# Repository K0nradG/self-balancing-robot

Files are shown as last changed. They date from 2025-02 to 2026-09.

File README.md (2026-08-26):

# Self-Balancing Robot

<p align="center">
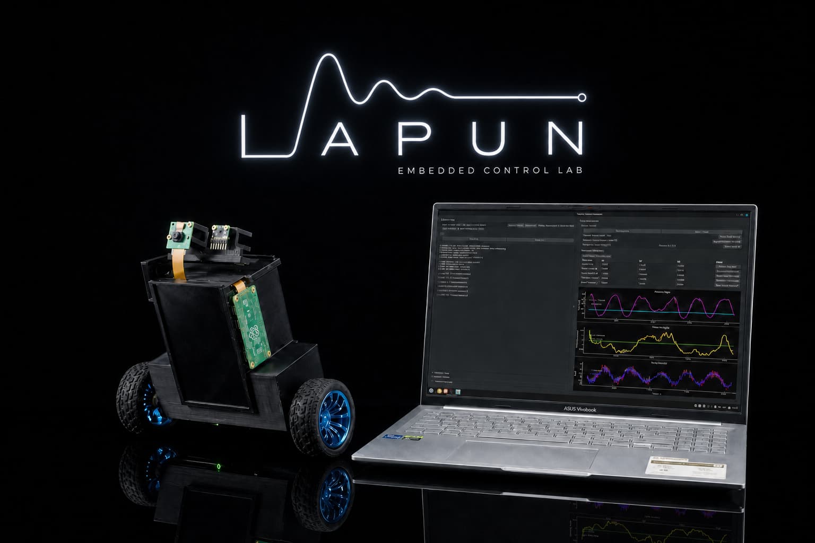
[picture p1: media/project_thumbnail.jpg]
Self-Balancing Robot and Control Application
  
</p>

A two-wheeled self-balancing robot built around the **Nordic nRF52840** and
**Zephyr RTOS**, using **nRF Connect SDK 2.8.0**. The project includes the
embedded control system, custom electronics and mechanical designs, a BLE
desktop application, over-the-air firmware updates, and tools for modelling
and controller development.

## Documentation

- [Project overview](README.md)
- [Environment setup](docs/environment_setup.md)
- [Building and flashing](docs/building_and_running_fw.md)
- [BLE protocol](Sources/drivers/bluetooth/README.md)
- [Control-loop structure](Sources/robot_control/docs/control_loop.md)
- [Application state machine](Sources/robot_control/docs/application_state_machine.md)
- [Mathematical model](mathematical_model/doc/model.md)

## Demonstration

https://github.com/user-attachments/assets/bdc0d3e3-bf6b-4125-bade-0684ad42b085

> 🎥 **See the robot in action!** 
> Check out the [Lapun Embedded Control Lab](https://youtube.com/@lapunembededcontrollab) on YouTube for more demonstrations.
>
> 

## Features

### Robot firmware

- Cascaded control loop for balancing, driving, and rotation
- PID controllers with user-adjustable setpoints and parameters
- Optional LQR balance controller
- Trajectory generation for linear motion and rotation
- MPU6050 inertial measurement and quadrature encoder feedback
- PWM motor control through a dual-channel TB6612FNG driver
- Battery-voltage monitoring
- Safety angle validation and controlled motor shutdown
- Binary BLE protocol for commands, telemetry, and diagnostic logs
- MCUboot-based device firmware update over BLE

### Control and development tools

- PyQt6 desktop application for BLE control, live telemetry, PID tuning, and DFU
- Offline model identification and LQR tuning tools
- MATLAB/Simulink models of the inverted-pendulum system
- Optional Raspberry Pi Zero 2 W web interface with camera streaming
- KiCad schematics, PCB layout, Gerber files, and mechanical CAD

> [!NOTE]
> The default firmware configuration uses PID control. The LQR controller and
> on-device model-identification mode are implemented but disabled by default.
>
> The Raspberry Pi web interface and the nRF7002 DK controller are legacy or
> experimental components and may require adaptation to the current binary BLE
> protocol.

## Control architecture

The firmware uses a cascaded control structure. Distance and linear-speed
controllers generate the balance-angle setpoint, while the balance and
rotation controllers determine the wheel-speed setpoints. Separate wheel
controllers then generate the motor PWM outputs.

Control loop architecture

## Hardware

The robot is based on:

- Nordic nRF52840 Dongle
- MPU6050 IMU
- Two DC gearmotors with quadrature encoders
- TB6612FNG dual motor driver
- 2-cell, 7.4 V LiPo battery
- Custom PCB and 3D-printed mechanical structure
- Optional Raspberry Pi Zero 2 W and CSI camera

Hardware design files are available in [`Schematic/`](Schematic/).

### Custom PCB

<p align="center">
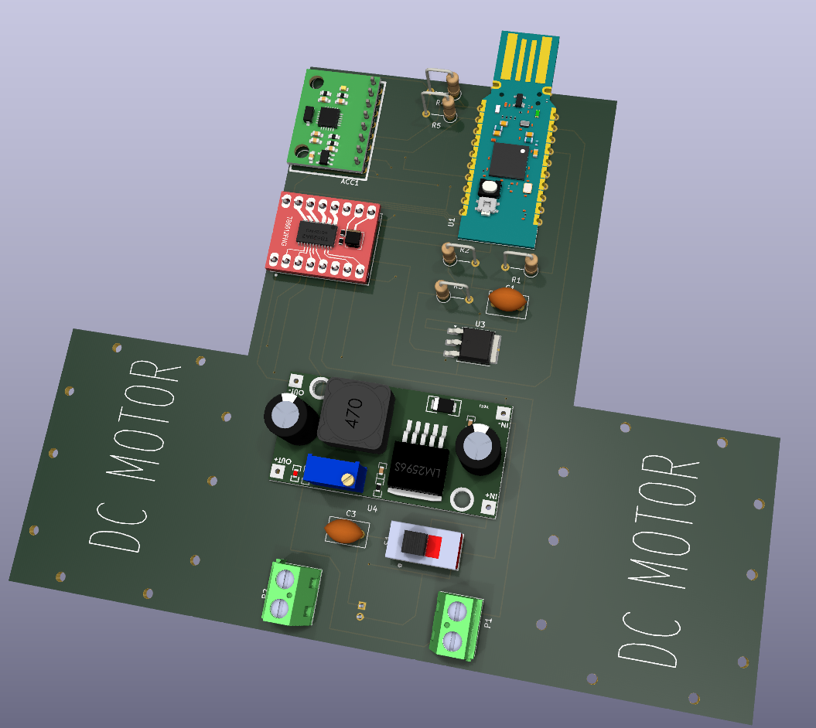
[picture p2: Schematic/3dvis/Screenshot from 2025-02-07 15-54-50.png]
Custom self-balancing robot PCB render
  
</p>

<p align="center"><em>3D render of the custom robot controller PCB.</em></p>

## Getting started

### Prerequisites

- [nRF Connect SDK 2.8.0](https://developer.nordicsemi.com/nRF_Connect_SDK/doc/2.8.0/nrf/index.html)
- nRF Connect toolchain 2.8.0
- West and the Zephyr development environment
- An external SWD debugger for the initial firmware installation

Follow the [environment setup guide](docs/environment_setup.md) before
building the project.

### Build the robot firmware

From the repository root:

```bash
cd Sources/applications/app
west build -b nrf52840dongle_nrf52840 -p always
```

A successful build generates:

```text
Sources/applications/app/build/merged.hex
Sources/applications/app/build/dfu_application.zip
```

The firmware can also be built through nRF Connect for VS Code. See
[Building and flashing](docs/building_and_running_fw.md) for the complete GUI,
terminal, SWD, and BLE DFU workflows.

### Flash the initial firmware

After connecting an external SWD debugger:

```bash
cd Sources/applications/app
west flash --erase --skip-rebuild
```

Subsequent firmware versions can be installed over BLE using the desktop
application or the command-line DFU tool.

### Run the desktop application

The desktop application requires Python 3, PyQt6, Bleak, and PyQtGraph:

```bash
python3 -m pip install PyQt6 bleak pyqtgraph
python3 run_controller_app.py
```

The DFU workflow additionally requires
[`smpmgr`](https://github.com/intercreate/smpmgr). A Windows binary is included
in [`3rdParty/smpmgr/`](3rdParty/smpmgr/); on Linux, `smpmgr` must be available
on `PATH`.

## Repository structure

```text
.
├── Sources/applications/app/          # Main nRF52840 robot firmware
├── Sources/applications/controller/   # Experimental nRF7002 DK controller
├── Sources/applications/controller_rpi/
│                                      # Raspberry Pi web interface
├── Sources/drivers/                   # IMU, encoders, motors, BLE, DFU, battery
├── Sources/robot_control/             # Control loop, PID, LQR, state machines
├── robot_control_app/                 # PyQt6 BLE desktop application
├── mathematical_model/                # Models, identification, and LQR tooling
├── Schematic/                         # PCB, schematics, Gerbers, and CAD
├── docs/                              # Setup and build documentation
└── dts/bindings/                      # Custom Zephyr devicetree bindings
```

## Roadmap

- Swing-up procedure
- Neural and other intelligent controllers
- Vision-based autonomous navigation

## Licensing

- Software and firmware: [Apache License 2.0](LICENSE)
- Hardware designs (schematics, PCB, and CAD):
  [CERN-OHL-P-2.0](Schematic/LICENSE)

Commercial use is permitted under the terms of the respective licenses.

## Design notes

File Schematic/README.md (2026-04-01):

## License

This project is licensed under the **CERN Open Hardware Licence Version 2 - Permissive (CERN-OHL-P)**. 

The license covers all design files in this directory, including:
* **Electronics:** KiCad schematics, PCB layouts, and libraries.
*  **Mechanics:** Physical case design (Fusion 360 files in the `robot-case` directory).

Copyright © 2026 Dymczyk Filip and Konrad Grucel

# **Project Based on KiCad 7.0**

## **Generating Gerber Files**

To generate new Gerber files after making changes to the schematic, follow [this guide](https://jlcpcb.com/help/article/how-to-generate-gerber-and-drill-files-in-kicad-7).

### **Quick Guide**

1. Open the PCB editor.
2. Click **File → Fabrication Outputs → Gerber Files (.gbr)**.
3. Your configuration should look like the following image:

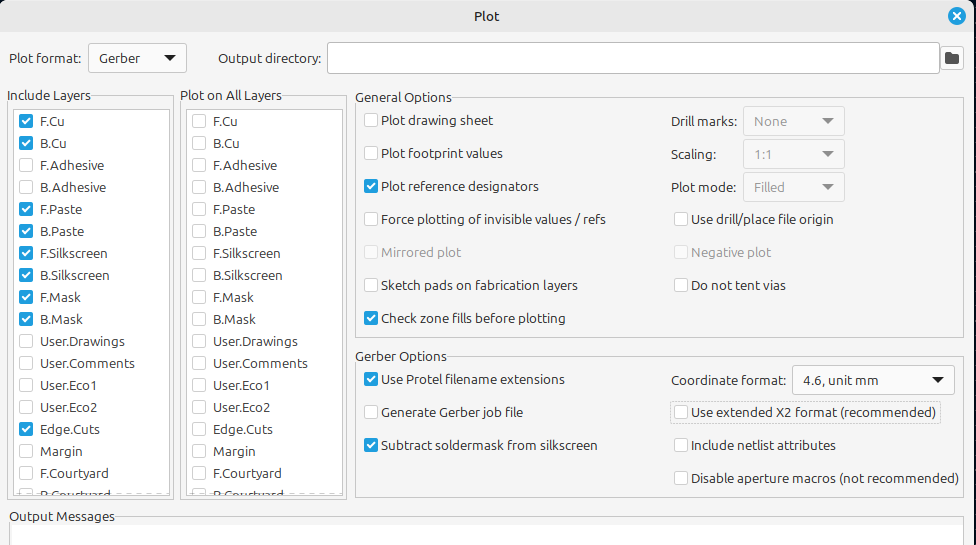
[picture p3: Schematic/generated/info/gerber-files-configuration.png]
.gbr files configuration


4. Click **Plot**, and the files will be saved in your selected output directory.

For drill files **.drl**, follow these steps:

1. Configure settings as shown below:

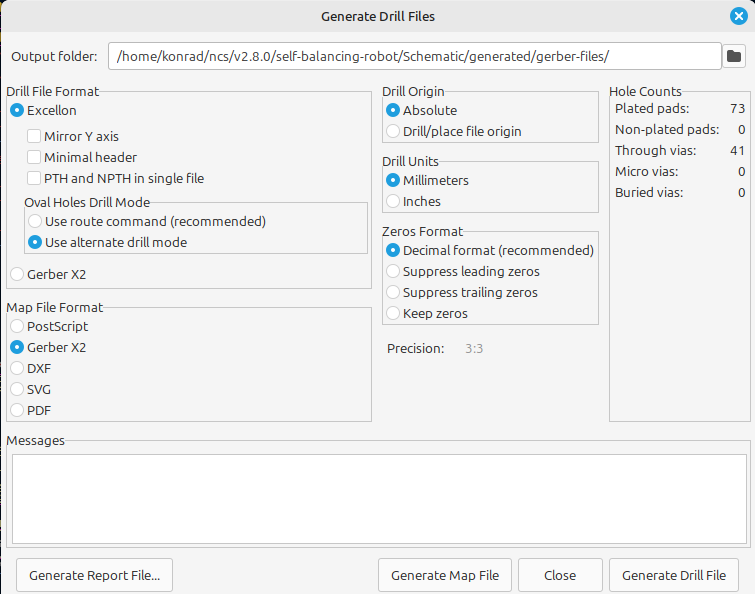
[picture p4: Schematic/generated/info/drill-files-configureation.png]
.gbr files configuration


1. Click **Generate Drill Files**, then **Generate Map Files**.
2. The files will be saved in your selected output directory.

**Adding Custom Symbols, Footprints, and 3D Models**

### **Sources for Custom Components**

You can find various custom symbols, footprints, and 3D models online. Recommended sources:

- [GrabCAD](https://grabcad.com/library/lm2596-module-for-kicad-1)
- [SnapEDA](https://www.snapeda.com/parts/GY-521/GODREAM FORDREAM CO., LIMITED/view-part)

All external symbols, footprints, and 3D models used in this project are located in the `external-3d-models` and `external-symbols-footprints` directories. The sources for these components are documented in `utils/external-parts-Kicad.txt`.

### **Adding Symbols and Footprints**

#### **1. Download the Files**

Example files from [SnapEDA](https://www.snapeda.com/parts/GY-521/GODREAM FORDREAM CO., LIMITED/view-part):

- **Symbol:** `.kicad_sym`
- **Footprint:** `.kicad_mod`

#### **2. Adding a Symbol**

1. Open the KiCad schematic editor.
2. Click **Preferences → Manage Symbol Libraries**.
3. Click the folder icon and provide the path to the `.kicad_sym` file.

#### **3. Adding a Footprint**

1. Open the KiCad schematic editor.

2. click the following icon

   .gbr files configuration

3. Click **Preferences → Manage footprints Libraries**,  and provide an path to the `.kicad_mod` file

next you have to click `Preferences button` button and then `Manage footprints liblaries`

then you have to click `directory(folder)` icon and provide a path to your `.kicad_mod` file.

**note: ** the `kicad_mod` and `kicad_sym` files can be in the same directory. if you download footprint and symbol package.

## **Adding 3D Models**

1. Download a 3D model, for example, from [GrabCAD](https://grabcad.com/library/mpu-6050-imu-sensor-1).
2. Place the corresponding symbol in the schematic.
3. Open the PCB editor and click **Tools → Update PCB from Schematic**.
4. Once the component appears, double-click it.
5. Navigate to the **3D Models** tab and provide the path to the `.wrl` or `.step` file.

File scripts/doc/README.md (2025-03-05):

# Python scripts overview

## `Clangd` issues fix

In order for `clangd` to work properly, `compile_commands.json` must be acquired from `CMake` build. The `get_compile_commands.py` takes the generated file from build directory and formats it by getting rid of flags not recognized by `clang`.

Whenever compilation warnings/errors occur, try running `get_compile_commands.py` script and reloading the VS Code window (ctrl + shift + p). This should fix the issues.

## General Serial Data Logging

- plug in NRF Dongle via USB cable,
- open `receive_serial_data.py` - modify `COM` port name (specific to Windows and Linux),
- run `receive_serial_data.py` script,
- press button on Dongle to start receiving through the script,
- once the sending is finished, data will be logged to `data/minicom.txt` file (can be changed in the script).

## Model Identification

To identify the model, first run the **`receive_serial_data.py`** script to gather data from the Dongle. Then, run the **`estimate_model.py`** script.

The result will be the estimated model parameters $ \alpha_1 $, $ \alpha_2 $, and $ \alpha_3 $, where:

- $ \alpha_1 = -\frac{b}{I} $ (damping coefficient over moment of inertia),
- $ \alpha_2 = \frac{m \cdot g \cdot l}{I} $ (gravitational term, based on the pendulum's mass, length, and gravitational acceleration),
- $ \alpha_3 = \frac{1}{I} $ (inverse of moment of inertia, affecting the control input).

These parameters are used in the state-space model of the inverted pendulum:

$$
\dot{x_1} = x_2
$$

$$
\dot{x_2} = \alpha_1 \cdot x_2 + \alpha_2 \cdot \sin(x_1) + \alpha_3 \cdot u
$$

Where:
- $ x_1 = \theta $ (the angle of deviation),
- $ x_2 = \dot{\theta} $ (the angular velocity),
- $ u $ (control input, the torque applied by the motor).

Using these parameters, you can further analyze or design a controller for the balancing robot.

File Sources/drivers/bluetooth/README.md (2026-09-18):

# Bluetooth protocol

The robot and the Python control application communicate through the Nordic UART Service (NUS) using binary RBT1 packets. All multi-byte values use little-endian byte order.

## Packet format

| Offset | Size | Field |
| ---: | ---: | --- |
| 0 | 4 | Magic value `RBT1` (`0x31544252`) |
| 4 | 1 | Message type |
| 5 | 1 | Reserved (currently zero) |
| 6 | 2 | Payload length |
| 8 | 4 | Packet number |
| 12 | variable | Message payload |

The header is 12 bytes. A packet contains exactly one header and one payload; RBT1 does not fragment or reassemble packets.

## Communication flow

- The Python application writes command packets to the NUS RX characteristic.
- The robot validates and handles each command, then normally sends a `COMMAND_RESULT` containing the request packet number, request type, and status.
- The robot independently sends telemetry, logs, and state notifications through the NUS TX characteristic.
- Telemetry and logs do not receive application-level acknowledgements.
- Protocol responses have priority over telemetry, which has priority over logs.

## Packet size and ATT MTU

The protocol supports packets up to 244 bytes because a commonly used ATT MTU of 247 bytes leaves `247 - 3 = 244` bytes for a GATT notification value. The 3 bytes are used by the ATT notification header.

The negotiated ATT MTU may be smaller. The firmware starts with the default 20-byte value limit (`ATT MTU 23 - 3`) and updates it after MTU exchange. Telemetry dynamically uses the largest batch of one to five samples that fits: five samples require a 240-byte ATT payload (MTU 243), while one sample requires 64 bytes (MTU 67). Below that limit telemetry cannot be sent because RBT1 does not fragment packets. Other packets larger than the current limit are rejected with `-EMSGSIZE`.

## Processing examples

### Log notification

For example, a robot module requests an `INF` log:

```cpp
robot_control_logger.platform_log(LOG_LEVEL::INF, "sample text");
```

The log follows this call path:

```text
Logger::platform_log("sample text")
    |
    v
vsnprintf() creates the text "sample text"
    |
    v
ble_send_log(INF, "ROBOT_CONTROL", "sample text")
    |
    v
get_log_module_length()
get_log_message_length()
    |
    v
write_log_payload()
    |
    v
put_packet_in_queue(log_tx_queue, LOG, payload)
    |
    v
check_packet_before_queue()
    |
    v
build_tx_packet()
    |
    v
k_msgq_put(log_tx_queue)
    |
    v
k_sem_give(tx_available)
    |
    v
tx_thread() wakes up
    |
    v
get_next_packet()
    |
    v
send_packet_to_nus()
    |
    v
bt_nus_send()
    |
    v
Python application
    |
    v
unpack_packet() checks the RBT1 frame
    |
    v
DataProcessor reads the LOG payload
    |
    v
GUI displays "[1] ROBOT_CONTROL: sample text"
```

The resulting packet is:

```text
RBT1 header:
  type           = LOG (0x02)
  payload_length = 28
  packet_number  = <robot TX packet number>

LOG payload:
  level          = INF (0x01)
  module_length  = 13
  text_length    = 11
  module         = "ROBOT_CONTROL"
  text           = "sample text"
```

The 12-byte header and 28-byte payload form one 40-byte NUS notification. The Python application checks the RBT1 header, reads the LOG payload, decodes both UTF-8 strings, and currently displays `[1] ROBOT_CONTROL: sample text`. Logs do not receive a `COMMAND_RESULT` response.

### Command and response

When the user clicks **Start Control**, the command and its response follow this call path:

```text
User clicks "Start Control"
    |
    v
ble_protocol.state_command(StateAction.START)
    |
    v
ble_protocol.pack_packet(STATE_COMMAND, START)
    |
    v
send_command_requested signal
    |
    v
BLEWorker.send_command()
    |
    v
unpack_packet() checks the command
    |
    v
pack_packet() adds the next app packet number
    |
    v
asyncio write queue
    |
    v
BLEWorker._write_loop()
    |
    v
BleakClient.write_gatt_char(NUS_RX, command, response=True)
    |
    v
Robot: nus_data_received()
    |
    v
BLE_Protocol::decode_packet()
    |
    v
send_received_packet_to_callback()
    |
    v
ble_packet_callback()
    |
    v
Robot_Controller::handle_ble_packet()
    |
    v
Payload_Reader::get_u8() reads START
    |
    v
Main_State_Machine::apply_command(START)
    |
    v
send_command_result()
    |
    v
ble_send_packet(COMMAND_RESULT)
    |
    v
put_packet_in_queue(protocol_tx_queue, COMMAND_RESULT, payload)
    |
    v
tx_thread() -> get_next_packet() -> send_packet_to_nus()
    |
    v
bt_nus_send()
    |
    v
Python: BLEWorker._notification_handler()
    |
    v
unpack_packet() checks the COMMAND_RESULT frame
    |
    v
DataProcessor._parse_command_result()
    |
    v
GUI displays the command status
```

`response=True` requests a GATT write response from BLE. It is separate from the RBT1 `COMMAND_RESULT`, which reports whether the robot accepted and applied the command.

Python sends this command packet:

```text
RBT1 header:
  type           = STATE_COMMAND (0x20)
  payload_length = 1
  packet_number  = 7

Payload:
  action         = START (0x00)
```

The robot decodes the packet, checks whether START is valid in its current state, applies it, and sends:

```text
RBT1 header:
  type           = COMMAND_RESULT (0x07)
  payload_length = 6
  packet_number  = <robot TX packet number>

Payload:
  request_packet_number = 7
  request_type          = STATE_COMMAND (0x20)
  status                = OK (0x00)
```

The response has its own robot TX packet number. Python matches the result to the request using `request_packet_number` inside the payload.

### Telemetry frame with five samples

With an ATT MTU of at least 243, the robot batches five samples collected at 2 ms intervals. The complete call path is:

```text
Robot_Controller::normal_motors_control()
    |
    v
creates one Telemetry_Sample
    |
    v
telemetry_submit(sample)
    |
    v
k_msgq_put(telemetry_queue)
    |
    v
telemetry_thread() receives the first sample
    |
    v
samples_per_frame(get_att_payload_size())
    |
    v
selects 5 samples for a large enough MTU
    |
    v
k_msgq_get() receives the remaining 4 samples
    |
    v
Payload_Writer writes dropped_samples, sample_count and reserved bytes
    |
    v
encode_sample() writes each of the 5 samples
    |
    v
ble_send_telemetry_packet()
    |
    v
put_packet_in_queue(telemetry_tx_queue, TELEMETRY, payload)
    |
    v
check_packet_before_queue()
    |
    v
build_tx_packet()
    |
    v
k_msgq_put(telemetry_tx_queue)
    |
    v
k_sem_give(tx_available)
    |
    v
tx_thread() wakes up
    |
    v
get_next_packet()
    |
    v
send_packet_to_nus()
    |
    v
bt_nus_send()
    |
    v
Python: BLEWorker._notification_handler()
    |
    v
unpack_packet() checks the TELEMETRY frame
    |
    v
DataProcessor._parse_telemetry()
    |
    v
reads sample_count and decodes all 5 samples
    |
    v
all samples can be written to CSV; the latest sample updates the GUI
```

The resulting telemetry packet is:

```text
RBT1 header                         12 bytes
  type           = TELEMETRY (0x01)
  payload_length = 228
  packet_number  = <telemetry packet number>

Telemetry metadata                  8 bytes
  dropped_samples = <total dropped>
  sample_count    = 5
  reserved        = 00 00 00

Five samples                      220 bytes
  each sample:
    timestamp_us                   4 bytes
    balance_setpoint               4 bytes (float)
    balance_angle                  4 bytes (float)
    rotation_setpoint              4 bytes (float)
    rotation_angle                 4 bytes (float)
    target_speed_0/1               8 bytes (2 floats)
    measured_speed_0/1             8 bytes (2 floats)
    pwm_0/1                        8 bytes (2 floats)

Complete RBT1 packet              240 bytes
```

The frame is sent every 10 ms. Python validates `payload_length`, reads `sample_count`, verifies that exactly `5 * 44` sample bytes remain, and decodes every timestamp and float. It then updates the UI and optionally writes all five samples to CSV. Telemetry is unacknowledged; packet-number gaps and `dropped_samples` indicate data loss.

The matching implementations are:

- Firmware: `include/ble_protocol.h` and `src/ble_protocol.cpp`
- Python: `robot_control_app/ble_protocol.py`

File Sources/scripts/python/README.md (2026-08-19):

# Raspberry Pi Zero 2 W Camera AP Provisioner

**provision_rpi_os_sd.py** python script automatically provisions an SD card for a Raspberry Pi Zero 2 W to run as a standalone wireless access point with a live camera RTSP/WebRTC stream.

---

## How It Works

The script automates the entire setup process by performing the following actions:
* Downloads the latest **Raspberry Pi OS Lite 32-bit** image.
* Downloads **MediaMTX** (ARMv7) from GitHub to handle high-performance video streaming.
* Flashes the image directly to the target SD card block device.
* Configures the filesystems on the SD card to set up:
  * A WPA2 Wi-Fi access point (`wlan0`) with a static IP address (`192.168.4.1`).
  * Headless **SSH access** enabled by default.
  * Automatic hardware-accelerated camera detection and an RTSP stream via MediaMTX (`rtsp://192.168.4.1:8554/camera`).

---

## Requirements & Fetched Tools

### Host Requirements
* A running **Linux** host system.
* **Root privileges** (`sudo`).
* Mandatory host command-line tools: `lsblk`, `mount`, `umount`, and `openssl`.

### Downloaded Assets
* **Raspberry Pi OS Lite 32-bit (armhf)** and its corresponding `.sha256` checksum file from official Raspberry Pi repositories.
* **MediaMTX** (`_linux_armv7.tar.gz`) from the official BlueEnviron GitHub releases API.

---

## Usage

1. Connect your micro-SD card reader with the SD card inserted into your Linux host.
2. Identify your target block device name using `lsblk` (e.g., `/dev/sdb`, **do not** choose a partition like `/dev/sdb1`).
3. Run the script with `sudo`, providing the target device:

```bash
sudo python3 provision_rpi_camera_sd.py --device /dev/sdX

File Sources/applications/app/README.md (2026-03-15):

# Memory report

To get the **memory report** execute:

    cd build
    ninja partition_manager_report

Result:

| Region | Start Address | Size (Hex) | Size | Description |
| --- | --- | --- | --- | --- |
| Flash | 0x00000000 | 0x100000 | 1024 kB | Total flash memory |
| MCUboot | 0x00000000 | 0x8000 | 32 kB | MCUboot bootloader |
| MCUboot Primary Slot | 0x00008000 | 0x7C000 | 496 kB  | Primary firmware slot |
| MCUboot Pad | 0x00008000 | 0x200 | 512 B | Image padding |
| Primary App | 0x00008200 | 0x7BE00 | 495 kB  | Application image |
| MCUboot Secondary Slot | 0x00084000 | 0x7C000 | 496 kB  | Secondary firmware slot |

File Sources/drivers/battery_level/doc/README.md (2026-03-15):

# LiPo 7.4V Battery Discharge Characteristics

This readme presents the **discharge characteristics of a LiPo 7.4V battery** and tests a function that calculates the battery charge level based on voltage.

## Battery Discharge Curve

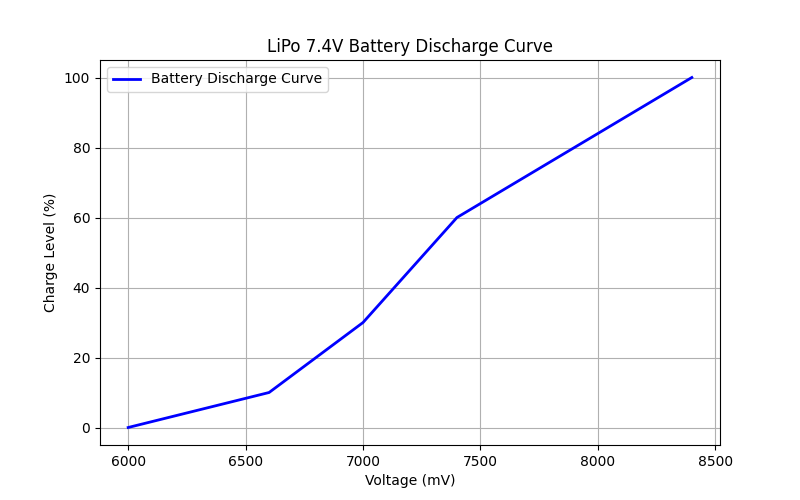
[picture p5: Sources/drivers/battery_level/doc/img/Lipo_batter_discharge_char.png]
discharge char


The graph illustrates the relationship between the battery charge level (%) and voltage (mV).

## Testing the Charge Level Function

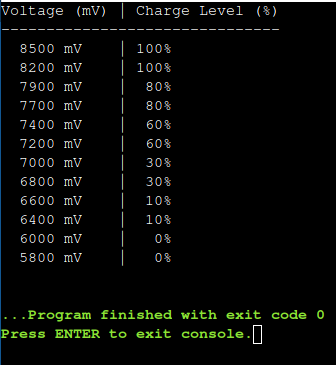
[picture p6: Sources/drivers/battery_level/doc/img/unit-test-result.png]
unit-test


The test of the `battery_charge_level()` function shows how the charge level changes based on the input voltage.

## Scripts

All scripts are located in the `doc/scripts` directory:

- `discharge_plot.py` – Python script generating the battery discharge curve.
- `battery_test.c` – C script testing the function that calculates the battery charge level.

## How to Use?

### 1️⃣ Generate the Discharge Graph in Python

Run the `discharge_plot.py` script:

```
python3 discharge_plot.py
```

### 2️⃣ Test the Function in C

Copy the `battery_test.c` code to your compiler or run it online:

- Go to [Online GDB](https://www.onlinegdb.com/online_c_compiler)
- Paste the code
- Click “Run”

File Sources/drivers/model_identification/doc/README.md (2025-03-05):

# Inverted Pendulum Parameter Identification and Transfer Function Derivation

## Project Description

The goal of this project is to identify the parameters of the **inverted pendulum model** (a two-wheeled balancing robot) and derive the transfer function of the system based on experimental data.

## Equation of Motion

The fundamental equation of motion for the inverted pendulum is:

$$
I \cdot \theta'' + b \cdot \theta' - mgl \cdot \sin(\theta) = \tau
$$

Where:
- $ \theta $ – the angle of deviation,
- $ \theta' $ – angular velocity,
- $ \theta'' $ – angular acceleration,
- $ \tau $ – control torque,
- $ I $ – moment of inertia,
- $ b $ – damping coefficient,
- $ m $ – mass of the pendulum,
- $ g $ – gravitational acceleration,
- $ l $ – distance from the pivot to the center of mass.

## State-Space Representation

Rewriting the equation of motion into state-space form:

$$
\dot{x_1} = x_2
$$

$$
\dot{x_2} = \frac{1}{I} (\tau - b \cdot x_2 - mgl \cdot \sin(x_1))
$$

Where:
- $ x_1 = \theta $ – angle of deviation,
- $ x_2 = \theta' $ – angular velocity,
- $ u = \tau $ – control input (torque).

The model with the identified parameters $ \alpha_1 $, $ \alpha_2 $, and $ \alpha_3 $ is as follows:

$$
\dot{x_2} = \alpha_1 \cdot x_2 + \alpha_2 \cdot \sin(x_1) + \alpha_3 \cdot u
$$

Where:
- $ \alpha_1 = -\frac{b}{I} $,
- $ \alpha_2 = \frac{mgl}{I} $,
- $ \alpha_3 = \frac{1}{I} $.

## Data Collection

To perform parameter identification, the following data must be collected:

1. **Control Input $ u(t) $** – The torque generated by the motors.
2. **System Outputs**:
   - $ \theta(t) $ – The angle of deviation (e.g., from an encoder or IMU),
   - $ \theta'(t) $ – Angular velocity (from a gyroscope or numerical differentiation of $ \theta(t) $),
   - $ \theta''(t) $ – Angular acceleration (numerical differentiation of angular velocity or from an accelerometer).

Data should be collected at a high sampling rate (e.g., 100-1000 Hz) and filtered to remove noise.

## Transfer Function Derivation

Based on the state-space equations, we can derive the transfer function $ G(s) $ of the system between the input $ u(t) $ and the output $ \theta(t) $ by applying the Laplace transform:

$$
G(s) = \frac{\Theta(s)}{U(s)} = \frac{\alpha_3}{I s^2 + \alpha_1 s + \alpha_2}
$$

Where:
- $ \Theta(s) $ is the Laplace transform of the angle $ \theta(t) $,
- $ U(s) $ is the Laplace transform of the control input $ u(t) $,
- $ \alpha_1 $, $ \alpha_2 $, $ \alpha_3 $ are the identified parameters.

## Model parameters

The identified parameters are as follows:

- $\alpha_1$ (damping): -4.1240
- $\alpha_2$ (gravity): -9.5838
- $\alpha_3$ (control): -14.4083

The angle predicted by the estimated model is compared to the measured data, as shown in the plot below:

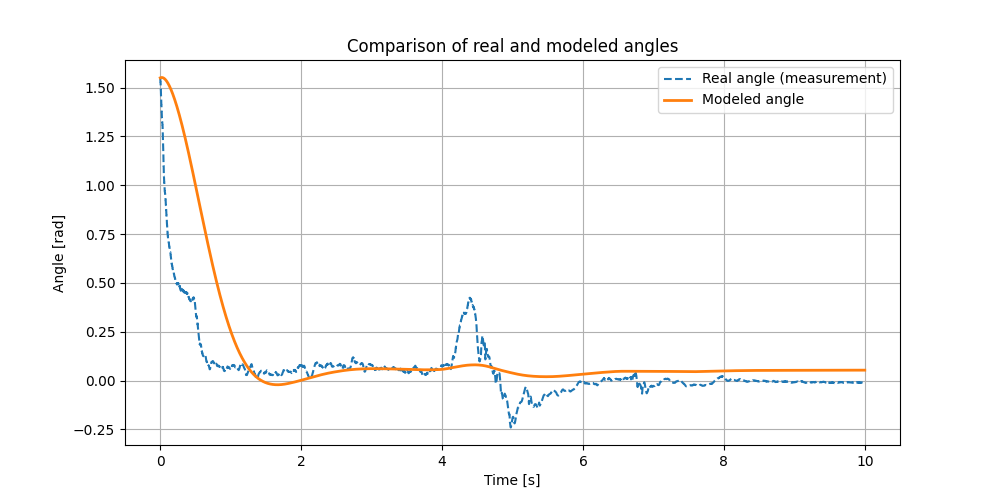
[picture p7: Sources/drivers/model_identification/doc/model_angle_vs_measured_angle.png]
Angle Comparison


The plot shows the system's response to a control signal from the PID controller. The model parameters were estimated based on this signal.

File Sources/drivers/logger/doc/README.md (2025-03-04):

# Connecting to a Bluetooth Device Using `bluetoothctl`

## Introduction

This guide explains how to connect to a Bluetooth device using `bluetoothctl`, enable scanning, and access GATT attributes.

## Requirements

- Linux with `bluetoothctl` installed (part of the `bluez` package)
- Bluetooth enabled on the computer
- Bluetooth device MAC address (e.g., `C6:57:6E:61:F2:06`)

## Steps

### 1. Start `bluetoothctl`

Open a terminal and enter:

```sh
bluetoothctl
```

### 2. Turn on Bluetooth

Enter the command:

```sh
power on
```

### 3. Enable device scanning

To find the Bluetooth device, enable scanning:

```sh
scan on
```

Wait about 10 seconds for the system to detect the device.

### 4. Connect to the device

Once the device is detected, connect to it using its MAC address:

```sh
connect C6:57:6E:61:F2:06
```

### 5. Enter the GATT menu

After successfully connecting, enter the GATT menu:

```sh
menu gatt
```

### 6. List device attributes

To see the list of GATT attributes:

```sh
list-attributes
```

### 7. Select a specific attribute

If you want to access a particular attribute, select it using its path, in our case it is an attribute which declares RX characteristic of NUS service.

```sh
select-attribute /org/bluez/hci0/dev_C6_57_6E_61_F2_06/service0010/char0011
```

### **8. Enable notyfications**

To perform this, type:

```sh
notify on
```

## Sending Data to the Device (TX Characteristic)

You can use the TX characteristic to send data to the device, for example, to update the parameters of a PID controller.

### Data Format:

```
k[k_gain]i[i_gain]d[d_gain]s[setpoint]
```

Where:

- `k_gain` – proportional gain (Kp)
- `i_gain` – integral gain (Ki)
- `d_gain` – derivative gain (Kd)
- `setpoint` – target setpoint value

### Example:

```
k3.4i2.1d7.3s-90
```

The above values set:

- `Kp = 3.4`
- `Ki = 2.1`
- `Kd = 7.3`
- `Setpoint = -90`

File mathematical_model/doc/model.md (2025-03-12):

## Inverted pendulum model

Model of **an inverted pendulum on a cart** (self-balancing robot) can be described by two differential equations. However, in our case we are only concerned about the model of the **inverted pendulum** itself - we are not controlling the robot position, but only trying to **balance** it:

$$
(I + m\ell^2) \ddot{\theta} = m\ell \ddot{x} \cos{\theta} - b \dot{\theta} + m g \ell \sin{\theta}.
$$

#### Where:
- $ I $ — moment of inertia of the pendulum about its center of mass [$\text{kg} \cdot \text{m}^2$],
- $ m $ — mass of the pendulum [$\text{kg}$],
- $ \ell $ — distance from the pivot point to the center of mass of the pendulum [$\text{m}$],    
- $ b $ — damping coefficient [$\text{N} \cdot \text{m} \cdot \text{s} / \text{rad}$],  
- $ g $ — gravitational acceleration [$\text{m/s}^2$].   

In our case, the center of mass was **very close** to the pivot point. That is why, we can simplify the equations by getting rid of **$ I $**, which after simplifications leads us to:

$$
\ell \ddot{\theta} = \ddot{x}\cos{\theta} - b \dot{\theta} + g \sin{\theta}.
$$

This equation was modeled in `pendulum_model.slx` Simulink file, for some random parameters from `simulation_data.m`, to test the model behavior. 

> **Note:** In order to run the simulation, launch the data file first.

It is also worth mentioning that for our purpose of later identification, simplified equation **won't lead** to any error, since it can be always written as:

$$
a \cdot \ddot{\theta} = b \cdot \ddot{x}\cos{\theta} + c \cdot \dot{\theta} + d \cdot \sin{\theta}.
$$

Where **a**, **b**, **c**, **d** are unknown coefficients to be identified.

Also, for **small angles** we can approximate:

$$
\sin(\theta) \approx \theta,\quad \cos(\theta) \approx 1.
$$

This leaves us with:

$$
\ell \ddot{\theta} = \ddot{x} - b \dot{\theta} + g \theta.
$$

Dividing by **$\ell$** gives us:

$$
\ddot{\theta} = \frac{\ddot{x}}{\ell} - \frac{b}{\ell} \dot{\theta} + \frac{g}{\ell} \theta.
$$

## Continuous transfer function
As mentioned before, we are **not** controlling the robot position. Thus, the **$\ddot{x}$** term is simply an input to our system. In `motor_controller` files we are controlling the motors by applying certain **PWM** level to them. Through that, we produce the input **$\ddot{x}$**, which can be obtained from:

$$
\ddot{x} = \frac{F}{m}, \quad \text{where} \quad F = k \cdot u.
$$

As we can see, the control input **u** (PWM signal) is directly related to the force driving the motors through some constant **k** (in simple linear case). This allows us to derive the **transfer function** for our system (assuming zero initial conditions):

$$
s^2 \Theta(s) = \frac{k}{m\ell} U(s) - \frac{b}{\ell} s \Theta(s) + \frac{g}{\ell} \Theta(s)
$$

Rearranging terms:

$$
\left( s^2 + \frac{b}{\ell} s - \frac{g}{\ell} \right) \Theta(s) = \frac{k}{m\ell} U(s).
$$

Solving for the transfer function:

$$ 
G(s) = \frac{\Theta(s)}{U(s)}.
$$

We get:

$$
G(s) = \frac{\frac{k}{m\ell}}{s^2 + \frac{b}{\ell} s - \frac{g}{\ell}}.
$$

It clearly shows that the open-loop system is unstable.

As we can see, there are 3 variables to be identified:

$$ 
a_1 = \frac{k}{m\ell}, \quad a_2 = \frac{b}{\ell}, \quad a_3 = -\frac{g}{l}.
$$

The system can be then written as:

$$
G(s) = \frac{a_1}{s^2 + a_2 s + a_3}.
$$

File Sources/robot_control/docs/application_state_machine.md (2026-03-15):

## Application State Machine structure



## States description
- **Perform DFU** – receives, verifies and loads new firmware. After a successful update, the robot reboots.
- **READY TO START** – waits for the start command. Until then, the robot is not balancing. 
- **OPERATION** – the main state in which the robot balances and receives driving and rotation commands.
- **SOFT STOP** – after an emergency or a regular stop command, PWM ramp-down to zero begins.
- **RESET CONTROL LOOP AFTER STOP** – resets the control loop and corresponding variables after stopping the robot.

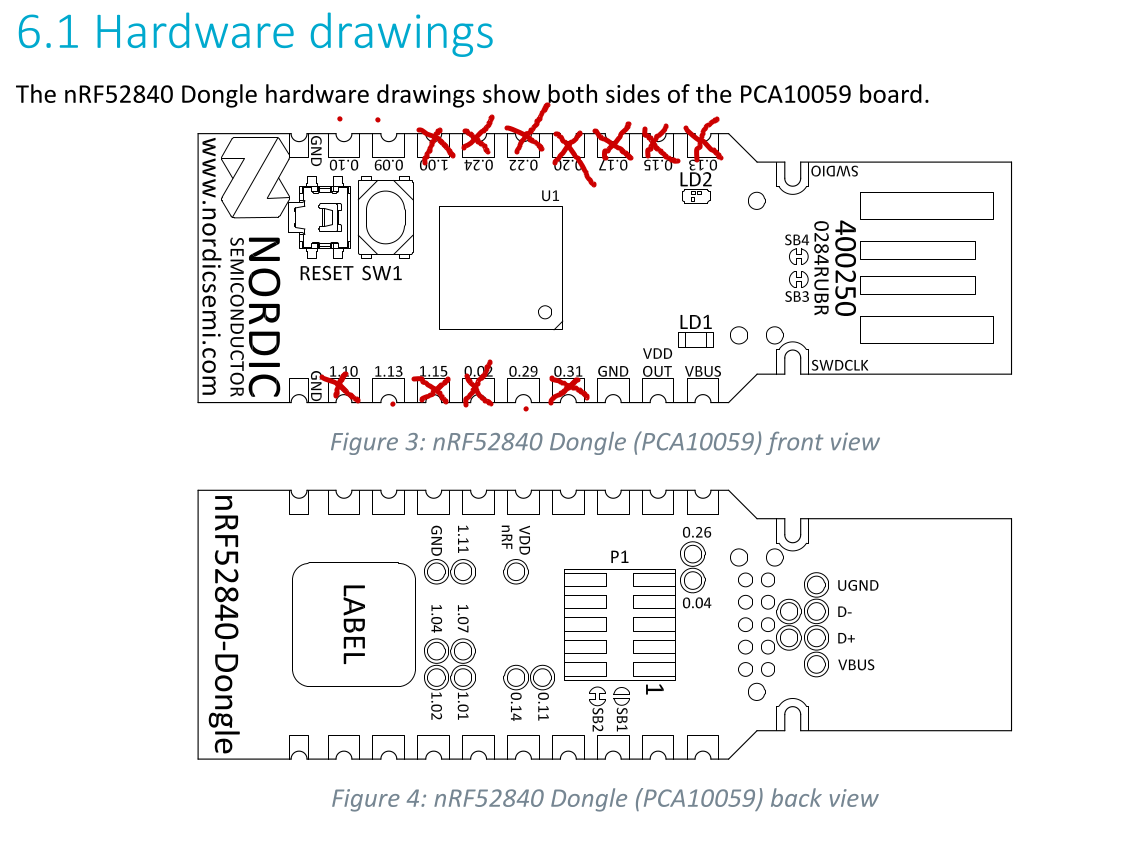
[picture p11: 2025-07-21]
Schematic/GPIOS/occupied-GPIOS.png

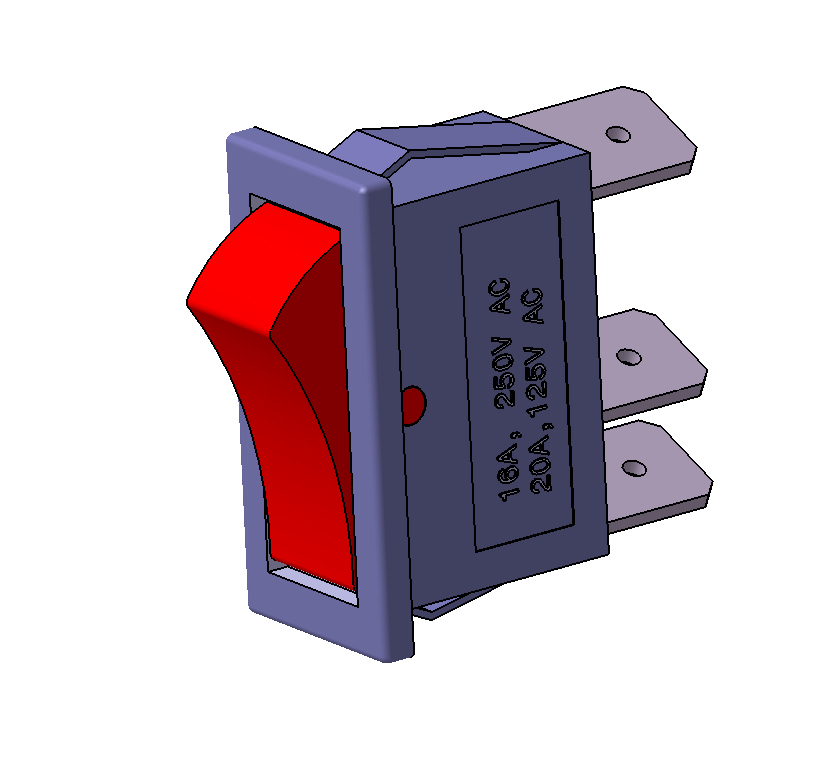
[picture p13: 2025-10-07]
Schematic/robot-case/external-models/spdt-rocker-switch-1.snapshot.2/SPDT SWITCH/SPDT ROCKER SWITCH.jpg

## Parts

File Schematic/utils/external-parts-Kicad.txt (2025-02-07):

nrf52840dongle:

symbol, footprint
https://www.snapeda.com/parts/NRF52840DONGLE/Nordic%20Semiconductor/view-part/?ref=search&t=nrf52840%20dongle

3d model
https://grabcad.com/library/nrf52840-dongle-1

MPU 6050 DFrobot

3d model
https://grabcad.com/library/mpu-6050-imu-sensor-1

symbol,footprint
https://www.snapeda.com/parts/GY-521/GODREAM%20FORDREAM%20CO.,%20LIMITED/view-part/

282837-2 (zlacze srubowe) (symbol,footprint,3d model)
https://www.snapeda.com/parts/282837-2/TE%20Connectivity%20AMP%20Connectors/view-part/?welcome=home

battery connectors

power supplier for dc motors

https://grabcad.com/library/lm2596-module-for-kicad-1

switch
https://www.digikey.it/en/models/67042

H bridge (foootprtint, symbol)

https://www.snapeda.com/parts/POLOLU-713/Pololu/view-part/

3D model
https://grabcad.com/library/doble-puente-h-tb6612fng-1

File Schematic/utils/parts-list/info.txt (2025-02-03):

https://docs.google.com/spreadsheets/d/1UMXaqWUqYby_AqKtbEk2MlvUZvl06K6HGAwR_36RCsY/edit?gid=0#gid=0

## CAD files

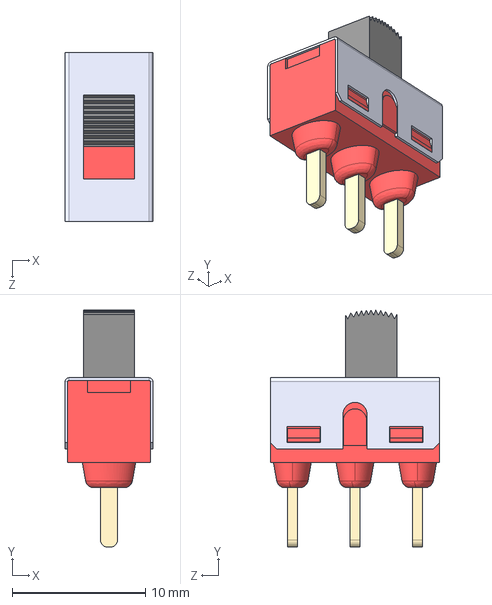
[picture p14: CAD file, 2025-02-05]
Schematic/external-3d-models/1101M2S3CQE2.snapshot/1101M2S3CQE2.step
6.60 x 17.8 x 12.7 mm

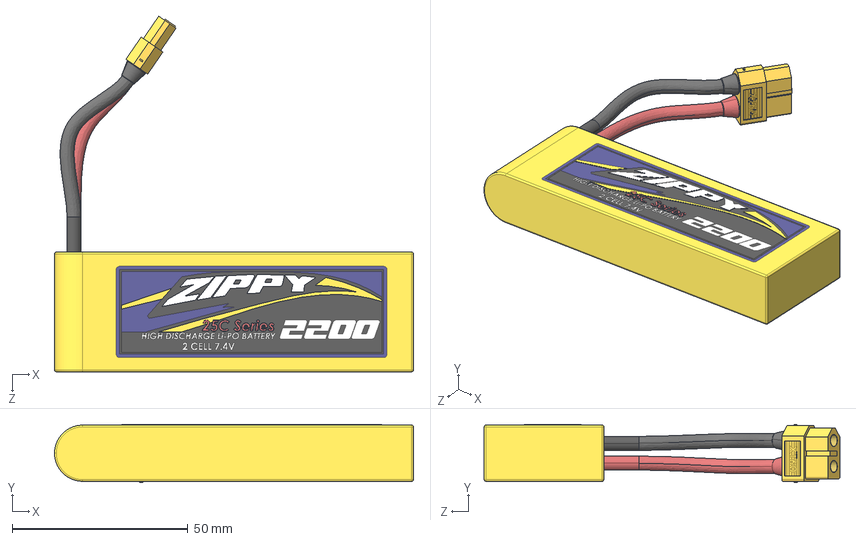
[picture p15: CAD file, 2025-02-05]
Schematic/external-3d-models/2s-7-4v-li-po-battery-1.snapshot.3/2S 7.4V Li-PO Battery.STEP
102.0 x 16.5 x 101.0 mm
Battery2S2200mAh25C
XT60MaleConnector
Battery Wiring^2S 7.4V Li-PO Battery

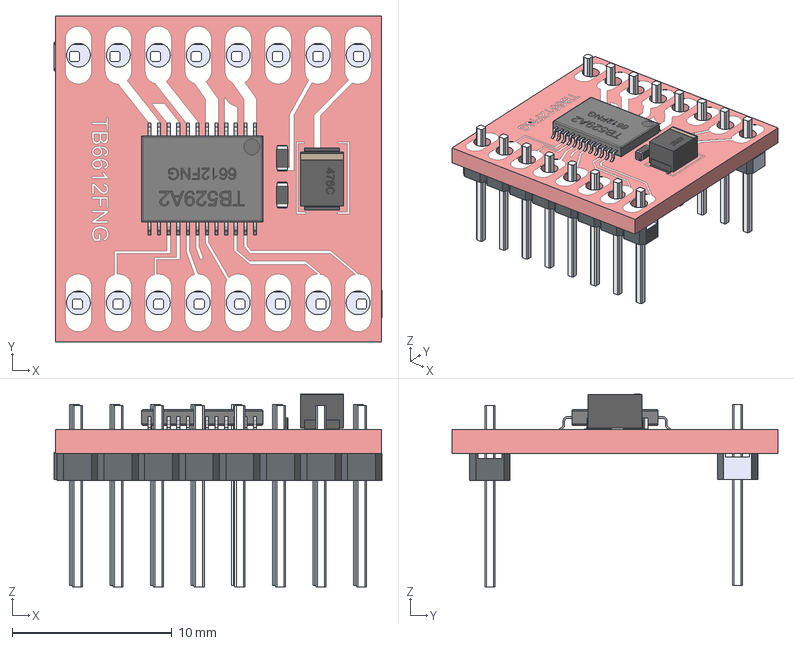
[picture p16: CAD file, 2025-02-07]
Schematic/external-3d-models/doble-puente-h-tb6612fng-1.snapshot.1/DOBLE PUENTE H.step
20.5 x 20.4 x 12.1 mm
TB6612FNG
capacitor
capacitor_v1 x 2
header_8 x 2

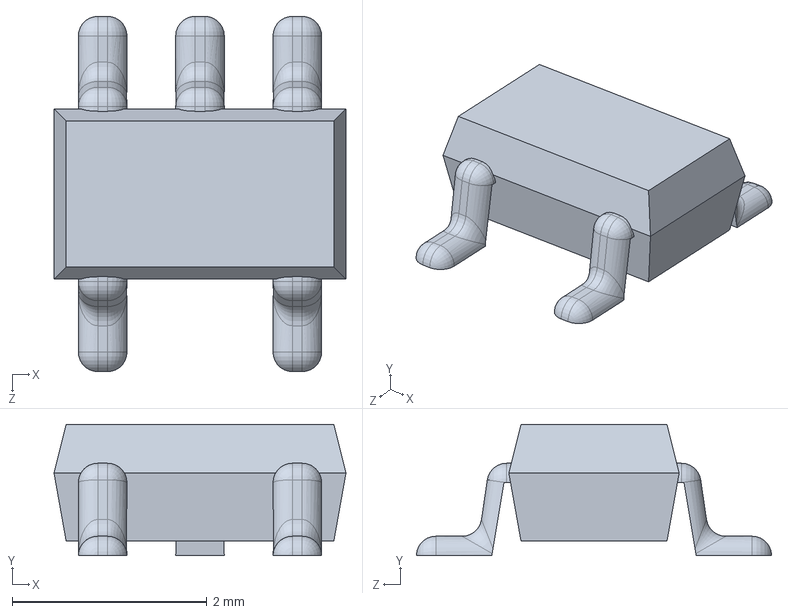
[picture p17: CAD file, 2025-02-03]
Schematic/external-3d-models/mpu-6050-imu-sensor-1.snapshot.5/S2NH chip.SLDPRT
3.00 x 1.35 x 3.65 mm

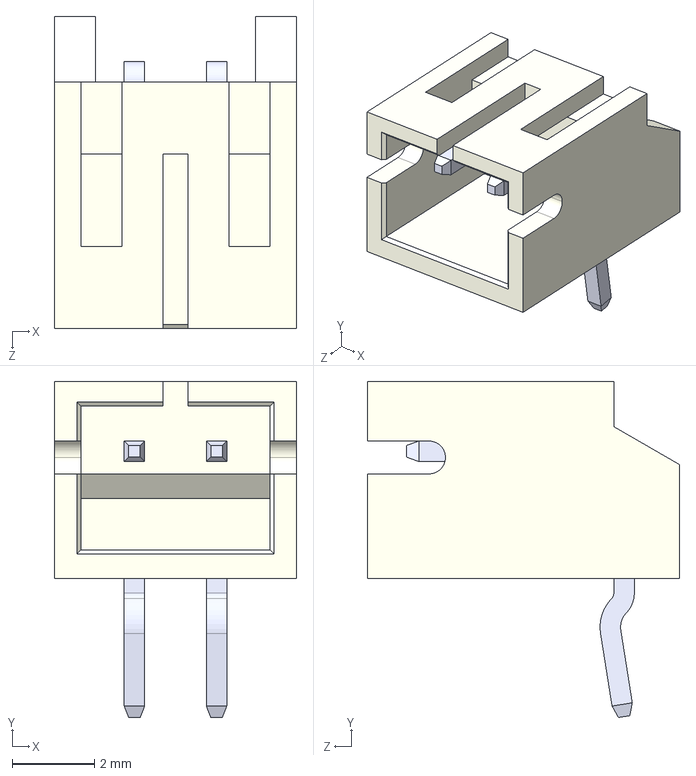
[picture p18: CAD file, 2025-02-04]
Schematic/external-3d-models/S2B-PH-K-S_LF__SN_.snapshot/S2B-PH-K-S(LF)(SN)--3DModel-STEP-1.STEP
5.90 x 8.18 x 7.60 mm

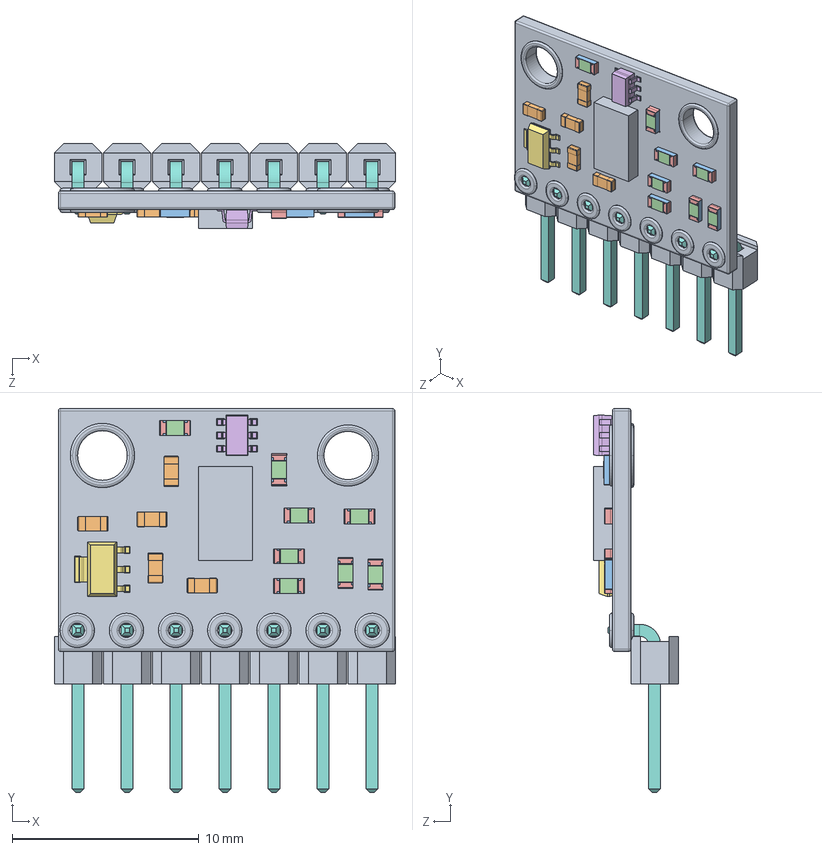
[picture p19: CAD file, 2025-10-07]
Schematic/robot-case/external-models/pololu-2489-1.snapshot.4/carte pololu 2489 .STEP
18.3 x 20.5 x 4.54 mm
VL6180X
603 cap on pad (2) x 5
603 NTC x 8
micro_reduit
Circuit integre reduit
7 pins coudées

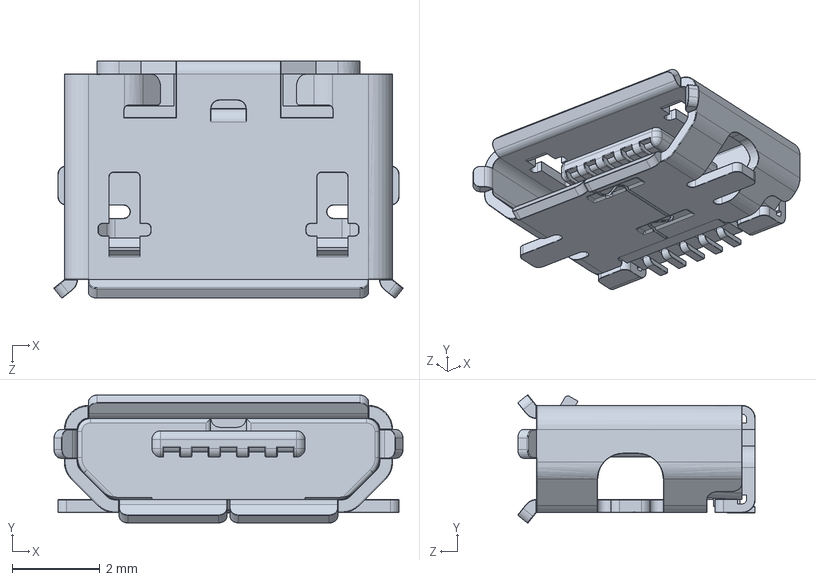
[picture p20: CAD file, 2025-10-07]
Schematic/robot-case/external-models/raspberry-pi-zero-2-w-1.snapshot.3/MicroUSB Port, Raspberry Pi Zero 2 W.SLDPRT
7.97 x 2.92 x 5.43 mm

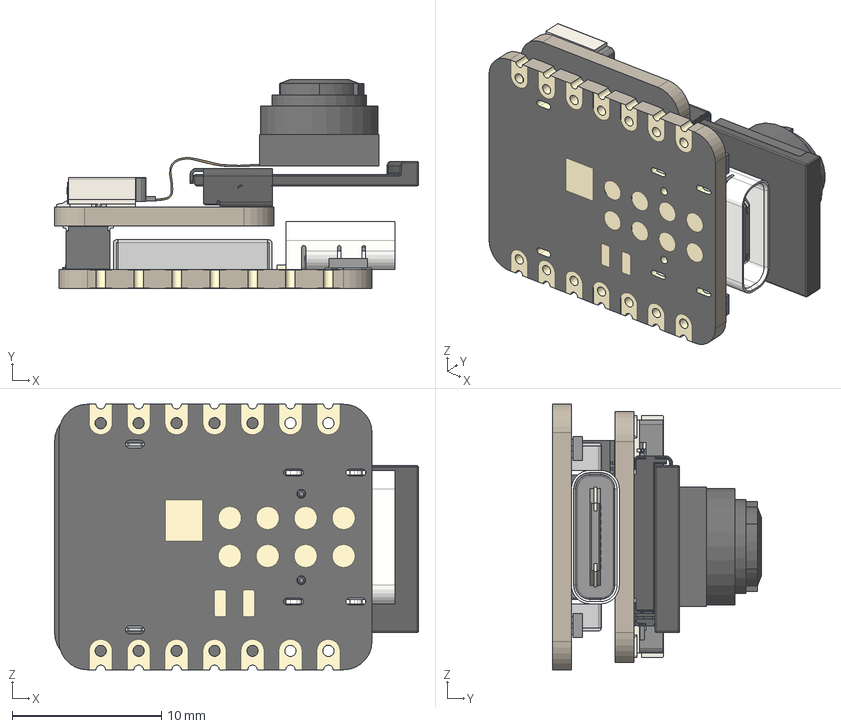
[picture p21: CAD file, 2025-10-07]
Schematic/robot-case/external-models/seeed-studio-xiao-esp32s3-sense-1.snapshot.2/Seeed Studio XIAO-ESP32-S3-Sense.step
24.4 x 14.0 x 17.8 mm
BOSS-EXTRUDE14_8_
BOSS-EXTRUDE7_4_
BOSS-EXTRUDE7_3_
BOSS-EXTRUDE14_4_
BOSS-EXTRUDE14_2_
BOSS-EXTRUDE14_11_
BOSS-EXTRUDE7_7_
BOSS-EXTRUDE14_9_
BOSS-EXTRUDE14_3_
BOSS-EXTRUDE14_7_
MIRROR2
BOSS-EXTRUDE14_5_
BOSS-EXTRUDE14_12_
BOSS-EXTRUDE7_8_
BOSS-EXTRUDE7_1_
BOSS-EXTRUDE14_10_
BOSS-EXTRUDE7_9_
BOSS-EXTRUDE14_6_
BOSS-EXTRUDE14_1_
BOSS-EXTRUDE7_6_
BOSS-EXTRUDE7_2_
CUT-EXTRUDE5
BOSS-EXTRUDE7_5_
Shield
Pins x 2
U.FL-R-SMT-1_10_ v1
DF40C-30DP-0.4V_51_ v1
DF40HC(3.0)-30DS
10067099-200LF v1
PCB
MicroSD v2
JUSHUO AFC01-S24FCA-00
Camer Module

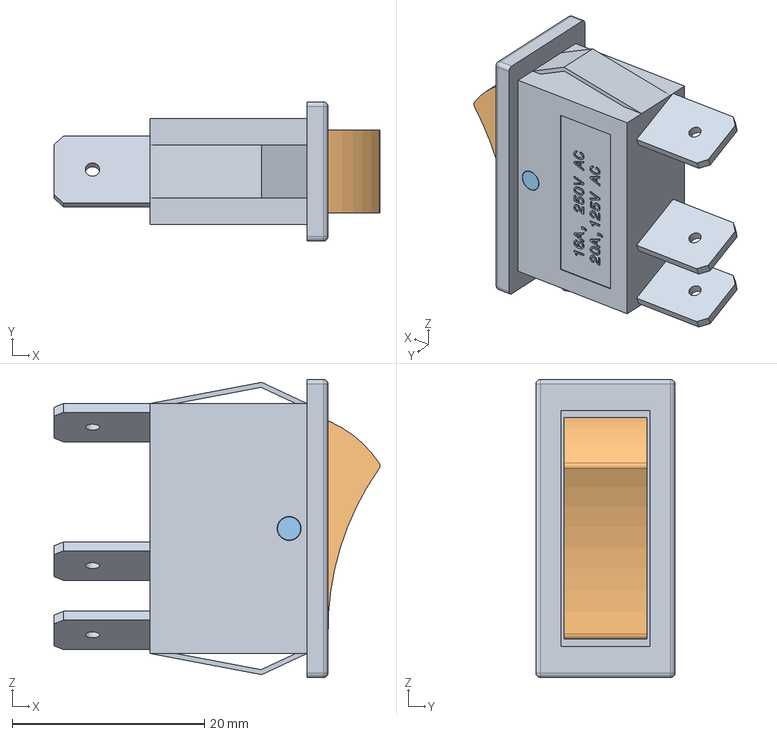
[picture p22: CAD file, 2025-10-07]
Schematic/robot-case/external-models/spdt-rocker-switch-1.snapshot.2/SPDT SWITCH/SPDT 30A switch.stp
33.9 x 14.5 x 31.0 mm

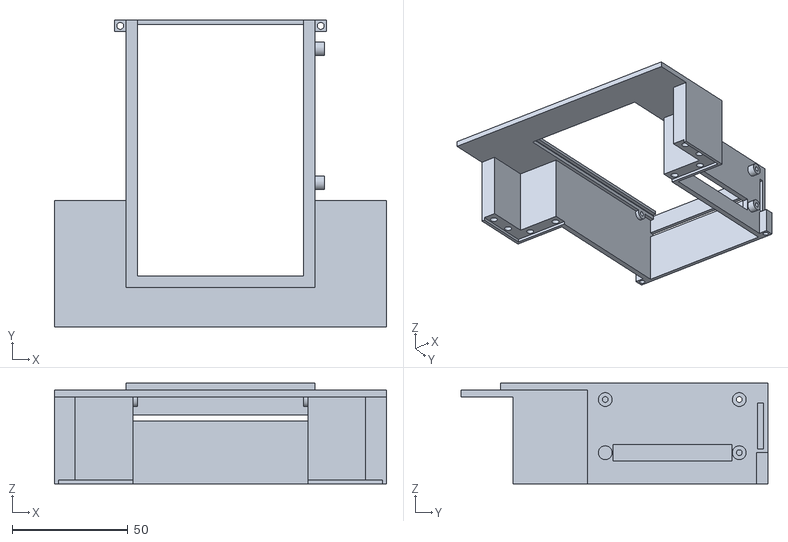
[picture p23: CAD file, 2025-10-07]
Schematic/robot-case/generated/obudowa_przod.stl
143.7 x 132.8 x 43.6

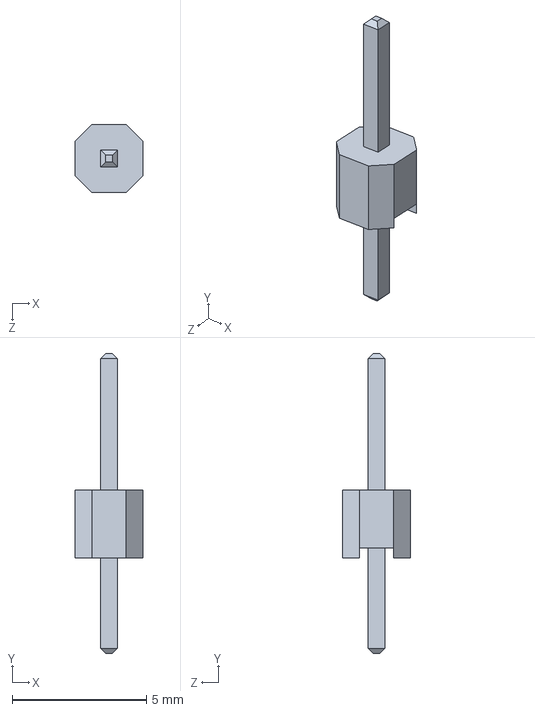
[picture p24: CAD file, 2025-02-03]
Schematic/external-3d-models/mpu-6050-imu-sensor-1.snapshot.5/pin header.SLDPRT
2.54 x 11.2 x 2.54 mm

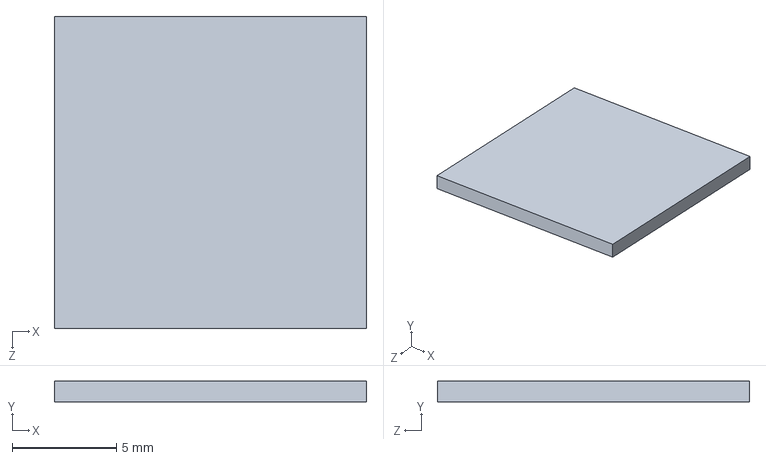
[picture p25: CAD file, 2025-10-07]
Schematic/robot-case/external-models/raspberry-pi-zero-2-w-1.snapshot.3/RP3A0-AU 2105 201221C, Raspberry Pi Zero 2 W.SLDPRT
15.0 x 1.00 x 15.0 mm

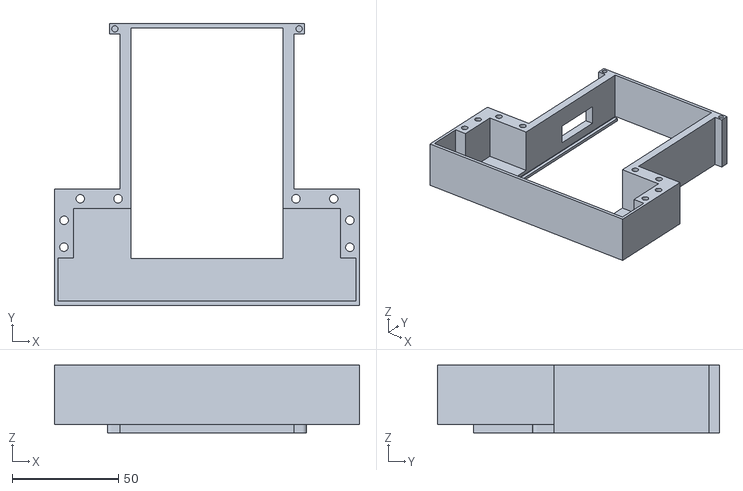
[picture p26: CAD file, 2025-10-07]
Schematic/robot-case/generated/obudowa_tyl.stl
143.7 x 132.8 x 32.0

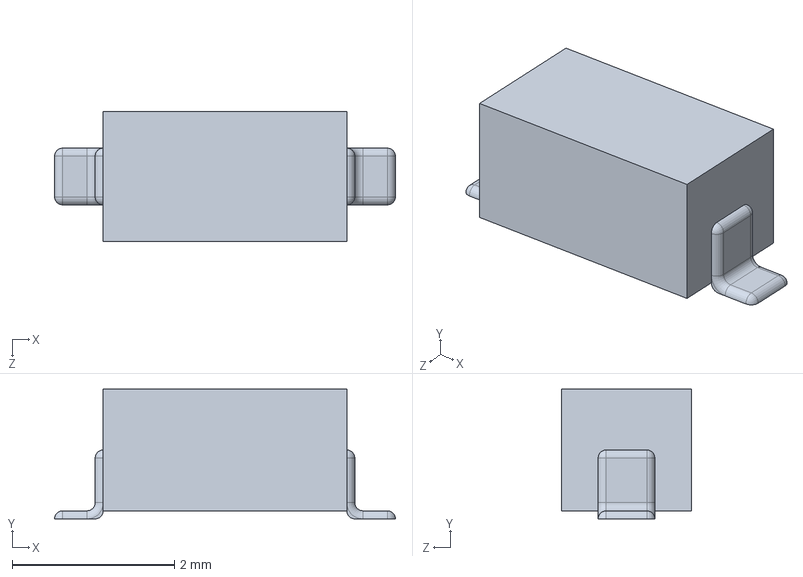
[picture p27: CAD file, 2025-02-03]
Schematic/external-3d-models/mpu-6050-imu-sensor-1.snapshot.5/Resistor black.SLDPRT
4.20 x 1.60 x 1.60 mm

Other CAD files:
Schematic/robot-case/generated/rpi-uchwyt2.stl
Schematic/external-3d-models/mpu-6050-imu-sensor-1.snapshot.5/Resistor small black.SLDPRT
Schematic/external-3d-models/282837-2.snapshot/282837-2--3DModel-STEP-269445.STEP
Schematic/external-3d-models/2s-7-4v-li-po-battery-1.snapshot.3/2S 7.4V Li-PO Battery.x_t
Schematic/external-3d-models/mpu-6050-imu-sensor-1.snapshot.5/Base.SLDPRT
Schematic/external-3d-models/mpu-6050-imu-sensor-1.snapshot.5/MPU 6050 IMU.SLDASM
Schematic/external-3d-models/mpu-6050-imu-sensor-1.snapshot.5/MPU 6050 IMU.STEP
Schematic/external-3d-models/mpu-6050-imu-sensor-1.snapshot.5/Resistor small.SLDPRT
Schematic/external-3d-models/mpu-6050-imu-sensor-1.snapshot.5/Small LED.SLDPRT
Schematic/external-3d-models/mpu-6050-imu-sensor-1.snapshot.5/sensor chip.SLDPRT
Schematic/external-3d-models/nrf52840-dongle-1.snapshot.1/nrf52840 dongle v4.step
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

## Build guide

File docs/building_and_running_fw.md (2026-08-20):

# Building and flashing

[Project overview](../README.md) |
[Environment setup](environment_setup.md) |
**Building and flashing**

This guide describes how to build the robot firmware with the nRF Connect
extension for Visual Studio Code or directly from a terminal. It also covers
the initial SWD flash and subsequent firmware updates over Bluetooth LE.

Complete the [environment setup](environment_setup.md) before continuing.

## Application and board

| Setting | Value |
| --- | --- |
| Application directory | `Sources/applications/app` |
| Board target | `nrf52840dongle_nrf52840` |
| nRF Connect SDK | v2.8.0 |
| Toolchain | v2.8.0 |
| Bootloader | MCUboot |

## Option 1: Build with nRF Connect for VS Code

1. Open the west workspace in Visual Studio Code.
2. Open the **nRF Connect** extension from the activity bar.
3. In the **Applications** view, select **Add an existing application**.
4. Select:

   ```text
   self-balancing-robot/Sources/applications/app
   ```

5. Select **Add build configuration** for the application.
6. Configure the build:
   - **Board:** `nrf52840dongle_nrf52840`
   - **SDK:** nRF Connect SDK v2.8.0
   - **Toolchain:** v2.8.0
   - **Build directory:** `build`
   - **Pristine build:** enabled for the first build
7. Select **Build configuration**.

The build output and available actions are displayed in the nRF Connect
extension. Later builds can use **Build** without recreating the
configuration. Use **Pristine Build** after changing the board, devicetree
overlays, Kconfig files, or SDK version.

## Option 2: Build from the terminal

Open a terminal with the nRF Connect SDK v2.8.0 environment active. You can
open one from nRF Connect for Desktop/Toolchain Manager, from the nRF Connect
extension, or configure the SDK environment manually.

From the repository root:

```bash
cd Sources/applications/app
west build -b nrf52840dongle_nrf52840 -p always
```

`-p always` performs a pristine build. For subsequent builds, run:

```bash
west build
```

To rebuild after changing CMake, Kconfig, or devicetree configuration:

```bash
west build -p always
```

To inspect or change Kconfig options interactively:

```bash
west build -t menuconfig
```

### Build helper script

The repository also provides a helper script:

```bash
python3 build_dongle_sw.py
```

Run it from the repository root in an nRF Connect terminal. The script:

1. formats files changed in the working tree,
2. builds `Sources/applications/app`,
3. retrieves `compile_commands.json` for `clangd`.

> [!IMPORTANT]
> The robot firmware helper is `build_dongle_sw.py`. The
> `Sources/scripts/python/build_dk_sw.py` script builds the separate nRF7002 DK
> controller application and must not be used for the robot firmware.

## Build artifacts

A successful build creates the `Sources/applications/app/build` directory.

| Artifact | Purpose |
| --- | --- |
| `build/merged.hex` | Complete image for the initial SWD flash, including MCUboot |
| `build/dfu_application.zip` | Signed application update package for DFU over BLE |

The DFU package contains the signed MCUboot application image. Do not use an
unsigned application image for DFU.

## Initial flash over SWD

The nRF52840 Dongle does not have an onboard debugger. The first complete
firmware installation, including MCUboot, requires an external SWD debugger.
The project has been tested using an nRF7002 DK as the debugger.

1. Connect the external debugger to the nRF52840 Dongle SWD signals.
2. Build the application.
3. From `Sources/applications/app`, run:

   ```bash
   west flash --erase --skip-rebuild
   ```

The same operation can be started from the repository root with:

```bash
python3 Sources/scripts/python/flash_dongle.py
```

`--erase` removes the previous flash contents. Use it for the initial
installation or when the partition layout changes. It also removes settings
stored in flash.

The nRF Connect extension can perform the equivalent operation through the
**Flash** action after a build configuration has been created and a supported
debug probe is connected.

## Firmware update over Bluetooth LE

After the initial SWD installation, application updates can be installed over
Bluetooth LE without opening the robot.

### Desktop application

1. Build the new firmware.
2. Start the desktop control application:

   ```bash
   python3 run_controller_app.py
   ```

3. Connect to `SELF_BALANCING_ROBOT`.

4. Start the update and keep the robot powered until it reboots and
   reconnects.

The desktop DFU workflow uses `smpmgr`. A Windows binary is included in
`3rdParty/smpmgr`; on Linux, `smpmgr` must be available on `PATH`.

### Command-line DFU

The same update can be started from the repository root:

```bash
python3 dfu_ble_dongle.py
```

By default, the script:

- connects to the BLE device named `SELF_BALANCING_ROBOT`,
- extracts `app.signed.bin` from `dfu_application.zip`,
- uploads and tests the image,
- resets the robot,
- reconnects and confirms the new image.

Use `--help` to list options such as a different BLE address or image:

```bash
python3 dfu_ble_dongle.py --help
```

### Raspberry Pi web interface

The Raspberry Pi Zero 2 W web application also contains a DFU workflow using
Newtmgr. This interface is a legacy/experimental component and may require
adaptation to the current binary BLE protocol. Prefer the desktop application
or `dfu_ble_dongle.py` for the current firmware.

## Troubleshooting

### `west: command not found`

Open a terminal from the nRF Connect v2.8.0 toolchain environment or activate
the SDK environment before building.

### Application or board not found

Confirm that west uses the correct workspace:

```bash
west topdir
west config manifest.path
```

The manifest path should point to `self-balancing-robot`, and the application
must be built from `Sources/applications/app`.

### Stale CMake, Kconfig, or devicetree configuration

Remove cached build configuration with a pristine rebuild:

```bash
west build -p always
```

### DFU package is missing

Confirm that the build completed successfully and that MCUboot is enabled.
Then check:

```text
Sources/applications/app/build/dfu_application.zip
```

### Memory report

After a successful build:

```bash
cd Sources/applications/app/build
ninja partition_manager_report
```

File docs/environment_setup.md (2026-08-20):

# Environment setup

[Project overview](../README.md) |
**Environment setup** |
[Building and flashing](building_and_running_fw.md)

This project is a Zephyr module and a west manifest repository based on
**nRF Connect SDK v2.8.0** and **nRF Connect toolchain v2.8.0**.

The environment can be configured through the nRF Connect extension for
Visual Studio Code or entirely from a terminal. Both workflows produce the
same west workspace and use the same build commands.

## Prerequisites

Install:

- [nRF Connect SDK v2.8.0](https://developer.nordicsemi.com/nRF_Connect_SDK/doc/2.8.0/nrf/installation/install_ncs.html)
- nRF Connect toolchain v2.8.0
- [nRF Connect for VS Code](https://marketplace.visualstudio.com/items?itemName=nordic-semiconductor.nrf-connect-extension-pack)
- Git

> [!NOTE]
> **nRF Connect for Desktop** and its Toolchain Manager can be used to install
> the SDK and open a terminal with the toolchain environment. The build
> integration inside the editor is provided by **nRF Connect for VS Code**.

## Option 1: Configure an existing NCS workspace in VS Code

Use this method if nRF Connect SDK v2.8.0 is already installed in a directory
such as `~/ncs/v2.8.0`.

1. Clone this repository into the SDK workspace:

   ```bash
   cd ~/ncs/v2.8.0
   git clone https://github.com/K0nradG/self-balancing-robot.git
   ```

2. Open `~/ncs/v2.8.0` in Visual Studio Code.
3. Open the **nRF Connect** extension.
4. Select **Manage West Workspace** and then
   **Switch West Manifest Repository**.
5. Select `self-balancing-robot/west.yml`.
6. Run **West Update** when prompted.
7. Select nRF Connect SDK and toolchain v2.8.0 for the workspace.

The resulting layout should contain:

```text
~/ncs/v2.8.0/
├── .west/
├── nrf/
├── zephyr/
└── self-balancing-robot/
```

## Option 2: Configure a new workspace from the terminal

Use a terminal in which the nRF Connect SDK v2.8.0 toolchain environment is
active. This can be a terminal opened from Toolchain Manager or the nRF
Connect extension.

```bash
west init \
  -m https://github.com/K0nradG/self-balancing-robot.git \
  --mr main \
  self-balancing-robot-workspace
cd self-balancing-robot-workspace
west update
west zephyr-export
```

The manifest imports the matching nRF Connect SDK revision automatically.
The repository is available at:

```text
self-balancing-robot-workspace/self-balancing-robot/
```

## Option 3: Switch an existing workspace from the terminal

If the repository has already been cloned into `~/ncs/v2.8.0`, the manifest
can be selected without using VS Code:

```bash
cd ~/ncs/v2.8.0
west config manifest.path self-balancing-robot
west update
west zephyr-export
```

Verify the environment before building:

```bash
west --version
west topdir
```

`west topdir` should print the root of the workspace containing
`self-balancing-robot`.

Continue with [Building and flashing](building_and_running_fw.md).

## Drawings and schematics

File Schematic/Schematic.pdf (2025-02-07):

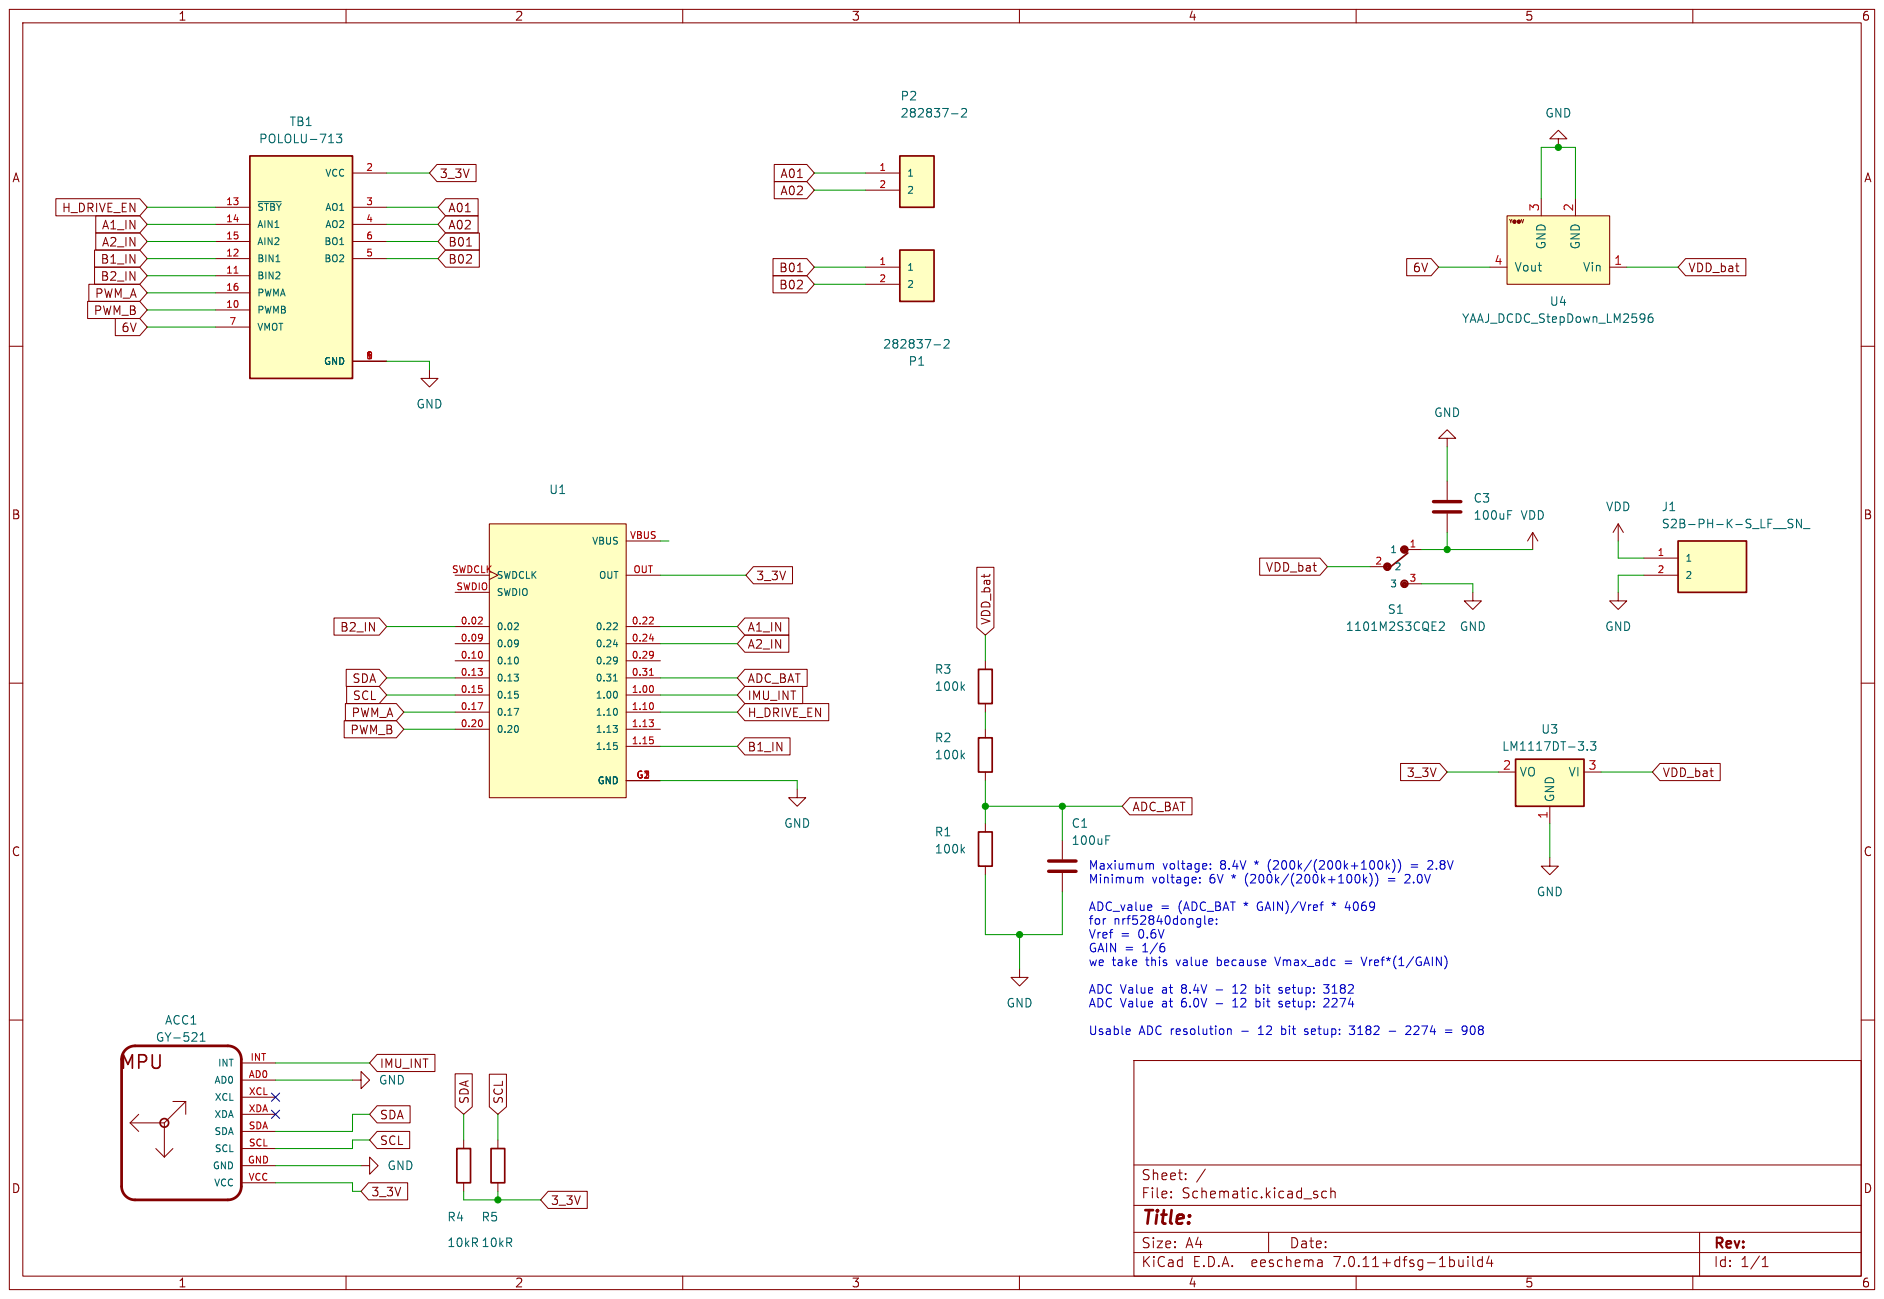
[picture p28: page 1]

Id: 1/1 Title: File: Schematic.kicad_sch Sheet: /

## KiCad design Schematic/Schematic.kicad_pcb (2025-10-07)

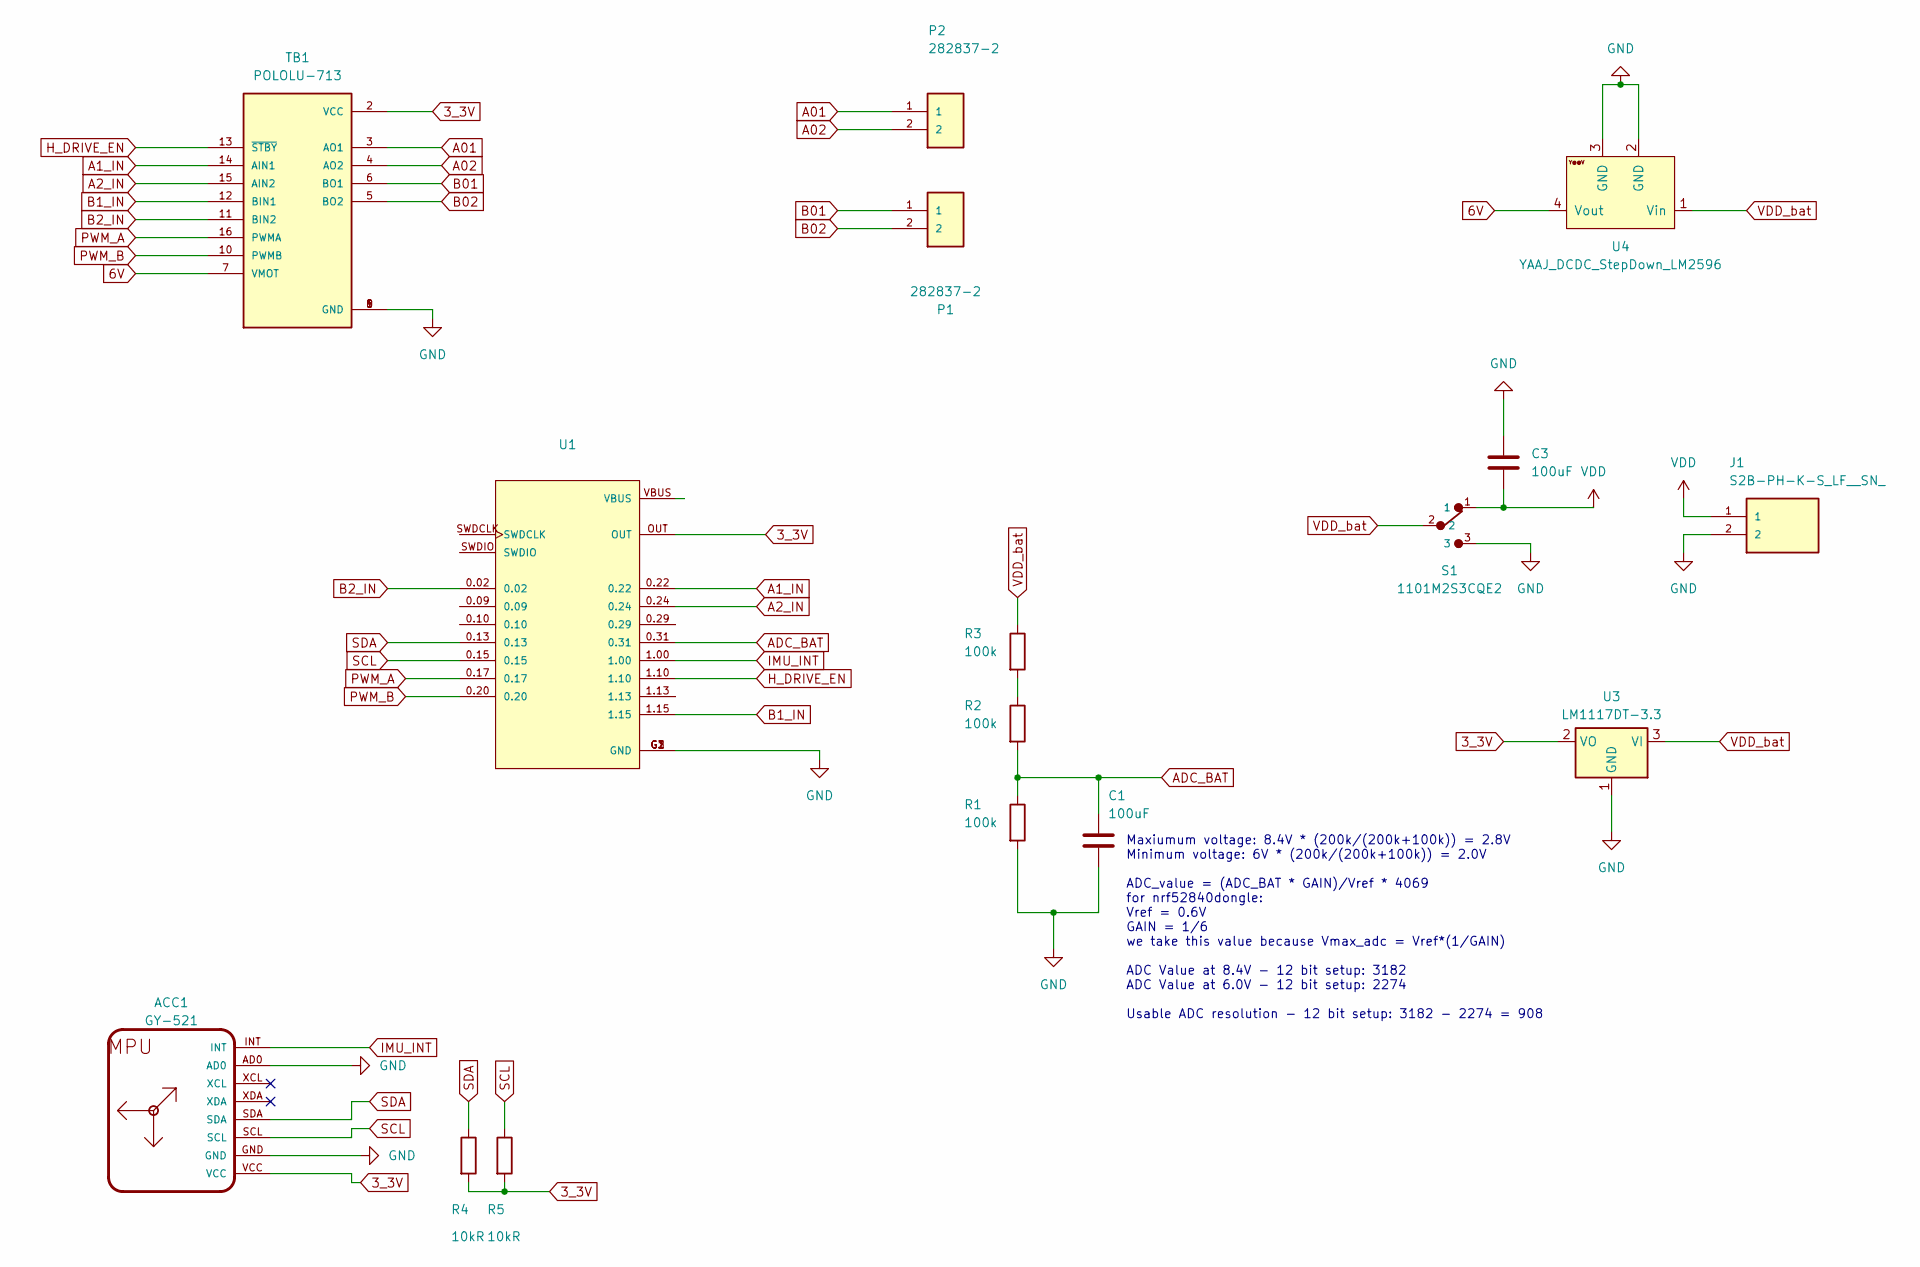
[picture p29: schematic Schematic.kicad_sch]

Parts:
ACC1: GY-521
C1, C3: 100uF; C_Disc_D7.5mm_W4.4mm_P5.00mm
J1: S2B-PH-K-S_LF__SN_; JST_S2B-PH-K-S_LF__SN_
P1, P2: 282837-2; TE_282837-2; PARTREV G3
R1, R2, R3: 100k; R_Axial_DIN0207_L6.3mm_D2.5mm_P5.08mm_Vertical
R4, R5: 10kR; R_Axial_DIN0207_L6.3mm_D2.5mm_P5.08mm_Vertical
S1: 1101M2S3CQE2; SW_1101M2S3CQE2
TB1: POLOLU-713; SHIELD_POLOLU-713
U1: NRF52840-DONGLE; MODULE_NRF52840-DONGLE
U3: LM1117DT-3.3; TO-252-3_TabPin2
U4: YAAJ_DCDC_StepDown_LM2596

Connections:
3_3V: ACC1.VCC, R4.2, R5.2, TB1.2 (VCC), U1.OUT, U3.2 (VO)
6V: TB1.7 (VMOT), U4.4 (Vout)
A01: P2.1, TB1.3 (AO1)
A1_IN: TB1.14 (AIN1), U1.0.22
A02: P2.2, TB1.4 (AO2)
A2_IN: TB1.15 (AIN2), U1.0.24
ADC_BAT: C1.1, R1.1, R2.2, U1.0.31
B01: P1.1, TB1.6 (BO1)
B1_IN: TB1.12 (BIN1), U1.1.15
B02: P1.2, TB1.5 (BO2)
B2_IN: TB1.11 (BIN2), U1.0.02
GND: ACC1.AD0, ACC1.GND, C1.2, C3.1, J1.2, R1.2, S1.3, TB1.1 (GND), TB1.8 (GND), TB1.9 (GND), U1.G1 (GND), U1.G2 (GND), U1.G3 (GND), U3.1 (GND), U4.2 (GND), U4.3 (GND)
H_DRIVE_EN: TB1.13 (~STBY), U1.1.10
IMU_INT: ACC1.INT, U1.1.00
unnamed: R2.1, R3.2
PWM_A: TB1.16 (PWMA), U1.0.17
PWM_B: TB1.10 (PWMB), U1.0.20
SCL: ACC1.SCL, R5.1, U1.0.15
SDA: ACC1.SDA, R4.1, U1.0.13
VDD: C3.2, J1.1, S1.1
VDD_bat: R3.1, S1.2, U3.3 (VI), U4.1 (Vin)

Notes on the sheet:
Maxiumum voltage: 8.4V * (200k/(200k+100k)) = 2.8V Minimum voltage: 6V * (200k/(200k+100k)) = 2.0V ADC_value = (ADC_BAT * GAIN)/Vref * 4069 for nrf52840dongle: Vref = 0.6V GAIN = 1/6 we take this value because Vmax_adc = Vref*(1/GAIN) ADC Value at 8.4V - 12 bit setup: 3182 ADC Value at 6.0V - 12 bi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

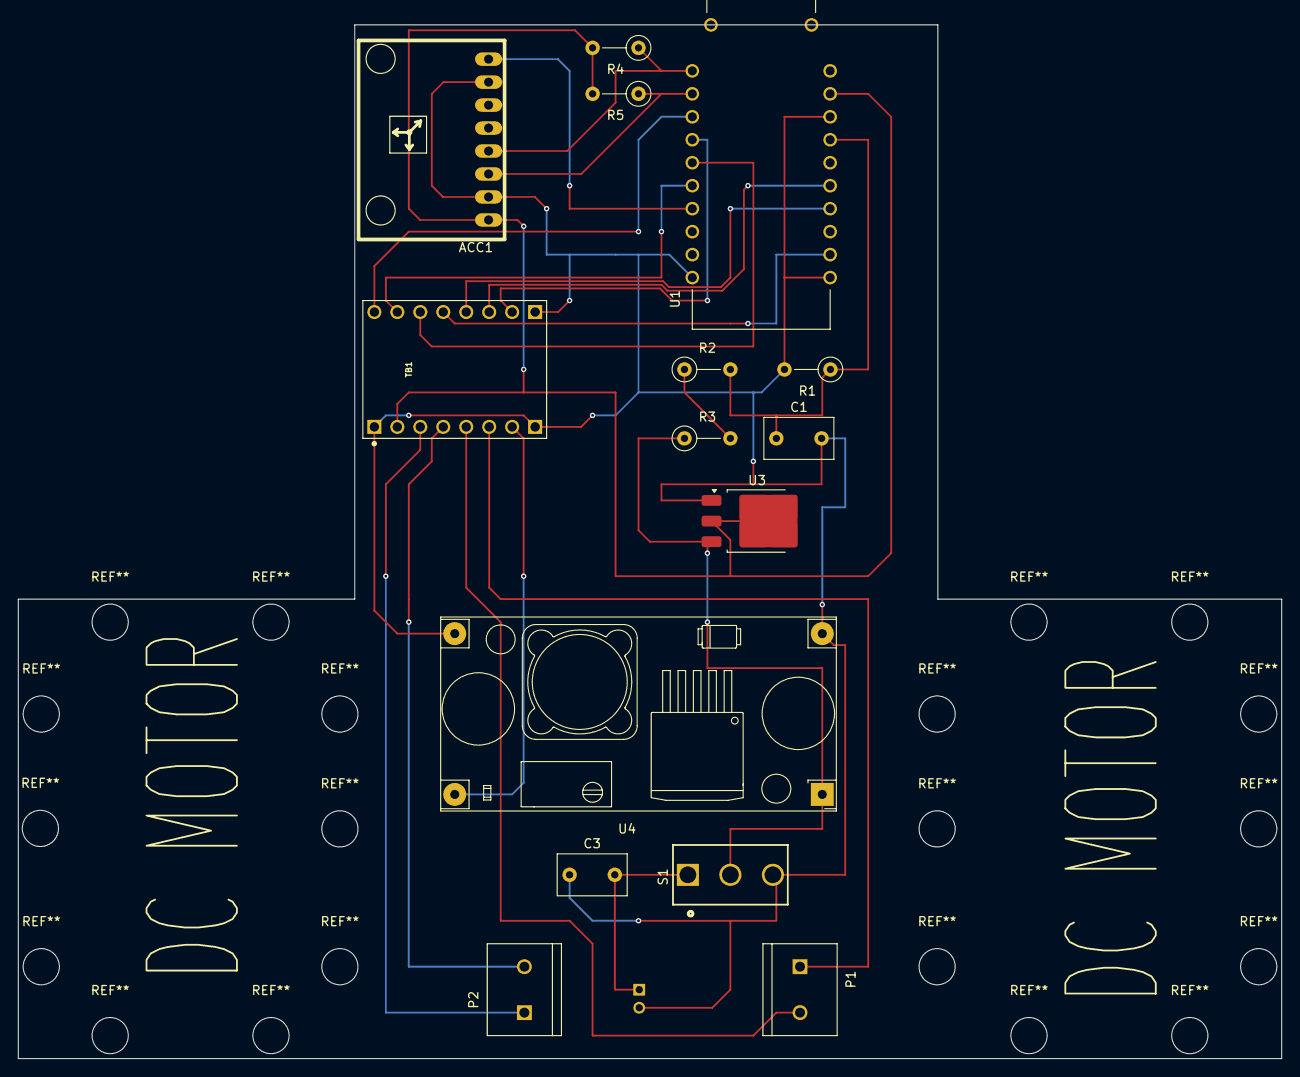
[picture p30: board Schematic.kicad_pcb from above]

Board: 2 copper layers, 139.7 x 114.3 mm, 16 parts (1 on the bottom side), 21 nets.

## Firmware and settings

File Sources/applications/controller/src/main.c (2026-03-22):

// Copyright 2026 Filip Dymczyk and Konrad Grucel

#include <bluetooth/gatt_dm.h>
#include <bluetooth/scan.h>
#include <bluetooth/services/nus.h>
#include <bluetooth/services/nus_client.h>
#include <dk_buttons_and_leds.h>
#include <zephyr/bluetooth/bluetooth.h>
#include <zephyr/bluetooth/conn.h>
#include <zephyr/bluetooth/gatt.h>
#include <zephyr/bluetooth/hci.h>
#include <zephyr/drivers/adc.h>
#include <zephyr/drivers/uart.h>
#include <zephyr/init.h>
#include <zephyr/kernel.h>
#include <zephyr/logging/log.h>
#include <zephyr/sys/printk.h>
#include "utils.h"

static const struct adc_dt_spec adc_channel = ADC_DT_SPEC_GET(DT_PATH(zephyr_user));

static int16_t adc_battery_buffer;

static struct adc_sequence sequence = {
    .buffer      = &adc_battery_buffer,
    .buffer_size = sizeof(adc_battery_buffer),
};

static struct k_work_delayable rotate_joystick_measurement_work;

static uint16_t measurement_interval;
static bool periodic_measurement_started;

#define UART_DEVICE_NODE DT_CHOSEN(zephyr_console)

const struct device* uart_dev = DEVICE_DT_GET(UART_DEVICE_NODE);

#define LOG_MODULE_NAME central_uart
LOG_MODULE_REGISTER(LOG_MODULE_NAME);

#define UART_BUFFER_SIZE 1u

static struct k_work_delayable uart_ble_work;
static uint8_t uart_buffer[UART_BUFFER_SIZE];

static struct bt_conn* default_conn;
static struct bt_nus_client nus_client;

static uint16_t rotate_step = 0u;

#define MS_TO_S       1000.0f
#define MAX_RAMP_STEP (float)((float)CONFIG_RAMP_RATE * ((float)CONFIG_JOYSTICK_SAMPLE_TIME / MS_TO_S))

static int
init(void)
{
    int ret;

    if(!adc_is_ready_dt(&adc_channel))
    {
        LOG_ERR("ADC Error");
        return -1;
    }

    ret = adc_channel_setup_dt(&adc_channel);
    if(ret < 0)
    {
        LOG_ERR("ADC Error");
        return ret;
    }

    ret = adc_sequence_init_dt(&adc_channel, &sequence);
    if(ret < 0)
    {
        LOG_ERR("ADC Error");
        return ret;
    }

    if(!sequence.buffer || sequence.buffer_size == 0)
    {
        LOG_ERR("ADC Error");
        return -1;
    }

    LOG_ERR("ADC init finished");

    return 0;
}

SYS_INIT(init, APPLICATION, CONFIG_APPLICATION_INIT_PRIORITY);

static int64_t
adc_get_sample(void)
{
    int ret = adc_sequence_init_dt(&adc_channel, &sequence);
    if(ret < 0)
    {
        LOG_ERR("init get sample err");
        return ret;
    }

    ret = adc_read(adc_channel.dev, &sequence);
    if(ret < 0)
    {
        LOG_ERR("read sample err");
        return ret;
    }

    int32_t battery_level_mv = adc_battery_buffer;

    ret = adc_raw_to_millivolts_dt(&adc_channel, &battery_level_mv);
    if(ret < 0)
    {
        LOG_ERR("convert sample err");
        return ret;
    }

    if(battery_level_mv > INT16_MAX)
    {
        LOG_ERR("range sample err");
        return -1;
    }
    const int64_t corrected_battery_level_mv = (int64_t)battery_level_mv;

    return corrected_battery_level_mv;
}

static float
voltage_to_angle(int64_t voltage_mv)
{
    return (((float)voltage_mv * 350.0f) / 1795.0f);
}

static void
send_nus_message(const char* message);

#define MAX_ANGLE_STEP_PER_CYCLE 1.0f

static void
joystick_measurement_work_handler(struct k_work* work)
{
    ARG_UNUSED(work);

    int64_t joystick_voltage = adc_get_sample();
    float target_angle       = voltage_to_angle(joystick_voltage);

    static float sum_angle;

    float diff = target_angle - sum_angle;

    if(fabsf(diff) > MAX_ANGLE_STEP_PER_CYCLE)
    {
        if(diff > 0)
        {
            sum_angle += MAX_RAMP_STEP;
        }
        else
        {
            sum_angle -= MAX_RAMP_STEP;
        }

        char angle_msg[16];
        snprintf(angle_msg, sizeof(angle_msg), "rs%.1f", sum_angle);
        send_nus_message(angle_msg);
    }

    LOG_INF("Voltage: %lld mV -> Target: %.2f deg, Output: %.2f deg", joystick_voltage, target_angle, sum_angle);

    reschedule_work(&rotate_joystick_measurement_work, K_MSEC(measurement_interval), "Battery level measurement");
}

static K_WORK_DELAYABLE_DEFINE(rotate_joystick_measurement_work, joystick_measurement_work_handler);

void
joystick_start_periodic_measurement(uint16_t interval_ms)
{
    if(periodic_measurement_started)
    {
        LOG_INF("worker started");
    }
    periodic_measurement_started = true;

    measurement_interval = interval_ms;
    reschedule_work(&rotate_joystick_measurement_work, K_NO_WAIT, "battery_level_measurement");
}

static void
send_nus_message(const char* message)
{
    int err;

    if(!default_conn)
    {
        LOG_WRN("Not connected; cannot send data");
        return;
    }

    err = bt_nus_client_send(&nus_client, message, strlen(message));
    if(err)
    {
        LOG_ERR("Failed to send data over NUS (err %d)", err);
    }
    else
    {
        LOG_INF("Sent: %s", message);
    }
}

static void
uart_ble_work_handler(struct k_work* work)
{
    uint8_t c = uart_buffer[0];
    char message[8];

    switch(c)
    {
        case 'r':
            rotate_step += 40;
            if(rotate_step > 320)
            {
                rotate_step = 320;
            }
            snprintf(message, sizeof(message), "rs%d", rotate_step);
            send_nus_message(message);
            break;

        case 'l':
            if(rotate_step <= 40)
            {
                rotate_step = 40;
            }
            else
            {
                rotate_step -= 40;
            }
            snprintf(message, sizeof(message), "rs%d", rotate_step);
            send_nus_message(message);
            break;

        case 'f':
            send_nus_message(CONFIG_DRIVE_FORWARD_COMMAND);
            break;

        default:
            LOG_WRN("Nieznany znak z UART: %c", c);
            break;
    }
}

static K_WORK_DELAYABLE_DEFINE(uart_ble_work, uart_ble_work_handler);

static void
uart_cb(const struct device* dev, void* user_data)
{
    uint8_t c;

    while(uart_fifo_read(dev, &c, 1))
    {
        LOG_INF("Received from UART: %c", c);
        uart_buffer[0] = c;
        k_work_submit(&uart_ble_work.work);
    }
}

static void
ble_data_sent(struct bt_nus_client* nus, uint8_t err, const uint8_t* const data, uint16_t len)
{
    ARG_UNUSED(nus);
    ARG_UNUSED(data);
    ARG_UNUSED(len);

    if(err)
    {
        LOG_WRN("ATT error code: 0x%02X", err);
    }
}

static void
button_handler(uint32_t button_state, uint32_t has_changed)
{
    if(has_changed & DK_BTN1_MSK)
    {
        if(button_state & DK_BTN1_MSK)
        {
            char message[8];
            snprintf(message, sizeof(message), "rs%d", rotate_step);
            send_nus_message(message);

            rotate_step += 40u;
            if(rotate_step > 320u)
            {
                rotate_step = 320u;
            }
        }
    }

    if(has_changed & DK_BTN2_MSK)
    {
        if(button_state & DK_BTN2_MSK)
        {
            if(rotate_step < 40u)
            {
                rotate_step = 40u;
            }
            else
            {
                rotate_step -= 40u;
            }

            char message[8];
            snprintf(message, sizeof(message), "rs%d", rotate_step);
            send_nus_message(message);
        }
    }
}

static uint8_t
ble_data_received(struct bt_nus_client* nus, const uint8_t* data, uint16_t len)
{
    ARG_UNUSED(nus);
    LOG_INF("Received data over BLE: %.*s", len, data);
    return BT_GATT_ITER_CONTINUE;
}

static void
discovery_complete(struct bt_gatt_dm* dm, void* context)
{
    struct bt_nus_client* nus = context;
    LOG_INF("Service discovery completed");

    bt_gatt_dm_data_print(dm);

    bt_nus_handles_assign(dm, nus);
    bt_nus_subscribe_receive(nus);

    bt_gatt_dm_data_release(dm);
}

static void
discovery_service_not_found(struct bt_conn* conn, void* context)
{
    LOG_INF("Service not found");
}

static void
discovery_error(struct bt_conn* conn, int err, void* context)
{
    LOG_WRN("Error while discovering GATT database: (%d)", err);
}

struct bt_gatt_dm_cb discovery_cb = {
    .completed         = discovery_complete,
    .service_not_found = discovery_service_not_found,
    .error_found       = discovery_error,
};

static void
gatt_discover(struct bt_conn* conn)
{
    int err;

    if(conn != default_conn)
    {
        return;
    }

    err = bt_gatt_dm_start(conn, BT_UUID_NUS_SERVICE, &discovery_cb, &nus_client);
    if(err)
    {
        LOG_ERR("could not start the discovery procedure, error code: %d", err);
    }
}

static void
exchange_func(struct bt_conn* conn, uint8_t err, struct bt_gatt_exchange_params* params)
{
    if(!err)
    {
        LOG_INF("MTU exchange done");
    }
    else
    {
        LOG_WRN("MTU exchange failed (err %" PRIu8 ")", err);
    }
}

static void
connected(struct bt_conn* conn, uint8_t conn_err)
{
    char addr[BT_ADDR_LE_STR_LEN];
    int err;

    bt_addr_le_to_str(bt_conn_get_dst(conn), addr, sizeof(addr));

    if(conn_err)
    {
        LOG_INF("Failed to connect to %s, 0x%02x %s", addr, conn_err, bt_hci_err_to_str(conn_err));

        if(default_conn == conn)
        {
            bt_conn_unref(default_conn);
            default_conn = NULL;

            err = bt_scan_start(BT_SCAN_TYPE_SCAN_ACTIVE);
            if(err)
            {
                LOG_ERR("Scanning failed to start (err %d)", err);
            }
        }

        return;
    }

    LOG_INF("Connected: %s", addr);

    static struct bt_gatt_exchange_params exchange_params;

    exchange_params.func = exchange_func;
    err                  = bt_gatt_exchange_mtu(conn, &exchange_params);
    if(err)
    {
        LOG_WRN("MTU exchange failed (err %d)", err);
    }

    gatt_discover(conn);

    err = bt_scan_stop();
    if((!err) && (err != -EALREADY))
    {
        LOG_ERR("Stop LE scan failed (err %d)", err);
    }
}

static void
disconnected(struct bt_conn* conn, uint8_t reason)
{
    char addr[BT_ADDR_LE_STR_LEN];
    int err;

    bt_addr_le_to_str(bt_conn_get_dst(conn), addr, sizeof(addr));

    LOG_INF("Disconnected: %s, reason 0x%02x %s", addr, reason, bt_hci_err_to_str(reason));

    if(default_conn != conn)
    {
        return;
    }

    bt_conn_unref(default_conn);
    default_conn = NULL;

    err = bt_scan_start(BT_SCAN_TYPE_SCAN_ACTIVE);
    if(err)
    {
        LOG_ERR("Scanning failed to start (err %d)", err);
    }
}

static void
security_changed(struct bt_conn* conn, bt_security_t level, enum bt_security_err err)
{
    char addr[BT_ADDR_LE_STR_LEN];

    bt_addr_le_to_str(bt_conn_get_dst(conn), addr, sizeof(addr));

    if(!err)
    {
        LOG_INF("Security changed: %s level %u", addr, level);
    }
    else
    {
        LOG_WRN("Security failed: %s level %u err %d %s", addr, level, err, bt_security_err_to_str(err));
    }

    gatt_discover(conn);
}

BT_CONN_CB_DEFINE(conn_callbacks) = {
    .connected        = connected,
    .disconnected     = disconnected,
    .security_changed = security_changed,
};

static void
scan_filter_match(struct bt_scan_device_info* device_info, struct bt_scan_filter_match* filter_match, bool connectable)
{
    char addr[BT_ADDR_LE_STR_LEN];

    bt_addr_le_to_str(device_info->recv_info->addr, addr, sizeof(addr));

    LOG_INF("Filters matched. Address: %s connectable: %d", addr, connectable);
}

static void
scan_connecting_error(struct bt_scan_device_info* device_info)
{
    LOG_WRN("Connecting failed");
}

static void
scan_connecting(struct bt_scan_device_info* device_info, struct bt_conn* conn)
{
    default_conn = bt_conn_ref(conn);
}

static int
nus_client_init(void)
{
    int err;
    struct bt_nus_client_init_param init = {
        .cb =
            {
                .received = ble_data_received,
                .sent     = ble_data_sent,
            },
    };

    err = bt_nus_client_init(&nus_client, &init);
    if(err)
    {
        LOG_ERR("NUS Client initialization failed (err %d)", err);
        return err;
    }

    LOG_INF("NUS Client module initialized");
    return err;
}

BT_SCAN_CB_INIT(scan_cb, scan_filter_match, NULL, scan_connecting_error, scan_connecting);

static int
scan_init(void)
{
    int err;
    struct bt_scan_init_param scan_init = {
        .connect_if_match = 1,
    };

    bt_scan_init(&scan_init);
    bt_scan_cb_register(&scan_cb);

    err = bt_scan_filter_add(BT_SCAN_FILTER_TYPE_NAME, CONFIG_TARGET_BLE_DEVICE_NAME);
    if(err)
    {
        LOG_ERR("Scanning filters cannot be set (err %d)", err);
        return err;
    }

    err = bt_scan_filter_enable(BT_SCAN_NAME_FILTER, false);
    if(err)
    {
        LOG_ERR("Filters cannot be turned on (err %d)", err);
        return err;
    }

    LOG_INF("Scan module initialized");
    return err;
}

int
main(void)
{
    if(!device_is_ready(uart_dev))
    {
        LOG_ERR("UART device not ready");
        return 0;
    }

    uart_irq_callback_user_data_set(uart_dev, uart_cb, NULL);
    uart_irq_rx_enable(uart_dev);

    int err;

    err = dk_buttons_init(button_handler);
    if(err)
    {
        LOG_ERR("dk_buttons_init failed (err %d)", err);
        return 0;
    }

    LOG_INF("Buttons and LEDs initialized");

    err = bt_enable(NULL);
    if(err)
    {
        LOG_ERR("Bluetooth init failed (err %d)", err);
        return 0;
    }
    LOG_INF("Bluetooth initialized");

    err = scan_init();
    if(err != 0)
    {
        LOG_ERR("scan_init failed (err %d)", err);
        return 0;
    }

    err = nus_client_init();
    if(err != 0)
    {
        LOG_ERR("nus_client_init failed (err %d)", err);
        return 0;
    }

    printk("Starting Bluetooth Central UART example\n");

    err = bt_scan_start(BT_SCAN_TYPE_SCAN_ACTIVE);
    if(err)
    {
        LOG_ERR("Scanning failed to start (err %d)", err);
        return 0;
    }

    LOG_INF("Scanning successfully started");

    joystick_start_periodic_measurement(CONFIG_JOYSTICK_SAMPLE_TIME);

    while(true)
    {
        k_sleep(K_SECONDS(1));
    }
}

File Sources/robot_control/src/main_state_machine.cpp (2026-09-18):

// Copyright 2026 Filip Dymczyk and Konrad Grucel

#include "main_state_machine.h"

#ifdef CONFIG_MODEL_IDENTIFICATION_DRV
#include "model_identification.h"
#endif  // CONFIG_MODEL_IDENTIFICATION_DRV

namespace Robot_Control
{

void
Main_State_Machine::update()
{
    if(m_state == IDENTIFICATION)
    {
        return;
    }

    switch(m_state)
    {
        case READY_TO_START:
            if(m_flags.start)
            {
                m_state = OPERATION;
            }
            break;
        case OPERATION:
            if(m_flags.disable_motors_command || m_flags.stop)
            {
                m_state = SOFT_STOP;
            }
            break;
        case SOFT_STOP:
            if(m_flags.motors_stopped)
            {
                m_state = RESET_AFTER_STOP;
            }
            break;
        case RESET_AFTER_STOP:
            m_state = READY_TO_START;
            break;
        default:
            break;
    }

    m_flags.reset();
}

Main_State_Machine::State
Main_State_Machine::get_state() const
{
    return m_state;
}

void
Main_State_Machine::set_disable_motors_command(bool disable_motors_command)
{
    m_flags.disable_motors_command = disable_motors_command;
}

void
Main_State_Machine::set_motors_stopped(bool motors_stopped)
{
    m_flags.motors_stopped = motors_stopped;
}

void
Main_State_Machine::set_stop_command()
{
    m_flags.stop = true;
}

bool
Main_State_Machine::apply_command(BLE_Protocol::State_Action action)
{
    switch(action)
    {
        case BLE_Protocol::State_Action::START:
            if(m_state == READY_TO_START)
            {
                m_flags.start = true;

#ifdef CONFIG_MODEL_IDENTIFICATION_DRV
                Model_Identification::instance().activate_identification();
#endif  // CONFIG_MODEL_IDENTIFICATION_DRV
                return true;
            }
            break;
        case BLE_Protocol::State_Action::STOP:
            if(m_state == OPERATION)
            {
                m_flags.stop = true;
                return true;
            }
            break;
        default:
            break;
    }
    return false;
}

}  // namespace Robot_Control

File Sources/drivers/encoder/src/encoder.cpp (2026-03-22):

// Copyright 2026 Filip Dymczyk and Konrad Grucel

#include "encoder.h"
#include <zephyr/device.h>
#include <zephyr/drivers/gpio.h>
#include <zephyr/kernel.h>
#include "logger.h"

#define M_PI        3.14159265358979323846f
#define WRAP_TO_2PI (2.0f * M_PI / CONFIG_IMPULSES_FOR_SHAFT_ROTATION)
#define MILLI_TO_SI 1.0f / 1000.0f

#define WHEEL_BASE_WIDTH_M (float)CONFIG_WHEEL_BASE_WIDTH_MM* MILLI_TO_SI
#define WHEEL_DIAMETER_M   (float)CONFIG_WHEEL_DIAMETER_MM* MILLI_TO_SI
#define WHEEL_RADIUS_M     WHEEL_DIAMETER_M / 2.0f

static Logger<IS_ENABLED(CONFIG_ENCODER_LOG)> encoder_logger("ENCODER");

static const gpio_dt_spec encoder_0_a = GPIO_DT_SPEC_GET(DT_NODELABEL(encoder_0), channel_a_gpios);
static const gpio_dt_spec encoder_0_b = GPIO_DT_SPEC_GET(DT_NODELABEL(encoder_0), channel_b_gpios);
static const gpio_dt_spec encoder_1_a = GPIO_DT_SPEC_GET(DT_NODELABEL(encoder_1), channel_a_gpios);
static const gpio_dt_spec encoder_1_b = GPIO_DT_SPEC_GET(DT_NODELABEL(encoder_1), channel_b_gpios);

static gpio_callback encoder_0_a_data;
static gpio_callback encoder_0_b_data;
static gpio_callback encoder_1_a_data;
static gpio_callback encoder_1_b_data;

static encoders_data g_encoders_data {};

// Lookup table: 16 entries for all possible transitions
// -1 = CCW, +1 = CW, 0 = invalid/bounce
static int8_t const transition_table[16u] = {
    0,   // 0000
    -1,  // 0001
    1,   // 0010
    0,   // 0011 (invalid)
    1,   // 0100
    0,   // 0101
    0,   // 0110 (invalid)
    -1,  // 0111
    -1,  // 1000
    0,   // 1001 (invalid)
    0,   // 1010
    1,   // 1011
    0,   // 1100 (invalid)
    1,   // 1101
    -1,  // 1110
    0    // 1111
};

void
encoder_0_gpio_callback(const device* dev, gpio_callback* cb, uint32_t pins)
{
    static uint8_t prev_state = 0u;

    bool const chan_a_state = gpio_pin_get_dt(&encoder_0_a);
    bool const chan_b_state = gpio_pin_get_dt(&encoder_0_b);

    uint8_t const curr_state = (chan_a_state << 1) | chan_b_state;
    uint8_t const transition = (prev_state << 2) | curr_state;

    int8_t const delta = transition_table[transition];
    g_encoders_data.encoder_0.impulse_count += delta;

    prev_state = curr_state;
}

void
encoder_1_gpio_callback(const device* dev, gpio_callback* cb, uint32_t pins)
{
    static uint8_t prev_state = 0u;

    bool const chan_a_state = gpio_pin_get_dt(&encoder_1_a);
    bool const chan_b_state = gpio_pin_get_dt(&encoder_1_b);

    uint8_t const curr_state = (chan_a_state << 1) | chan_b_state;
    uint8_t const transition = (prev_state << 2) | curr_state;

    int8_t const delta = transition_table[transition];
    g_encoders_data.encoder_1.impulse_count += delta;

    prev_state = curr_state;
}

int
encoders_init()
{
    if(!device_is_ready(encoder_0_a.port) || !device_is_ready(encoder_0_b.port) || !device_is_ready(encoder_1_a.port) ||
       !device_is_ready(encoder_1_b.port))
    {
        encoder_logger.platform_log(LOG_LEVEL::ERR, "encoder not ready");
        return -ENODEV;
    }

    int ret = gpio_pin_configure_dt(&encoder_0_a, GPIO_INPUT);
    ret |= gpio_pin_configure_dt(&encoder_0_b, GPIO_INPUT);
    ret |= gpio_pin_configure_dt(&encoder_1_a, GPIO_INPUT);
    ret |= gpio_pin_configure_dt(&encoder_1_b, GPIO_INPUT);

    if(ret != 0)
    {
        encoder_logger.platform_log(LOG_LEVEL::ERR, "Encoder pins not ready");
        return ret;
    }

    ret |= gpio_pin_interrupt_configure_dt(&encoder_0_a, GPIO_INT_EDGE_BOTH);
    ret |= gpio_pin_interrupt_configure_dt(&encoder_0_b, GPIO_INT_EDGE_BOTH);

    ret |= gpio_pin_interrupt_configure_dt(&encoder_1_a, GPIO_INT_EDGE_BOTH);
    ret |= gpio_pin_interrupt_configure_dt(&encoder_1_b, GPIO_INT_EDGE_BOTH);

    if(ret != 0)
    {
        encoder_logger.platform_log(LOG_LEVEL::ERR, "Failed to configure pins interrupts");
        return ret;
    }

    gpio_init_callback(&encoder_0_a_data, encoder_0_gpio_callback, BIT(encoder_0_a.pin));
    ret |= gpio_add_callback(encoder_0_a.port, &encoder_0_a_data);
    gpio_init_callback(&encoder_0_b_data, encoder_0_gpio_callback, BIT(encoder_0_b.pin));
    ret |= gpio_add_callback(encoder_0_b.port, &encoder_0_b_data);

    gpio_init_callback(&encoder_1_a_data, encoder_1_gpio_callback, BIT(encoder_1_a.pin));
    ret |= gpio_add_callback(encoder_1_a.port, &encoder_1_a_data);
    gpio_init_callback(&encoder_1_b_data, encoder_1_gpio_callback, BIT(encoder_1_b.pin));
    ret |= gpio_add_callback(encoder_1_b.port, &encoder_1_b_data);

    if(ret != 0)
    {
        encoder_logger.platform_log(LOG_LEVEL::ERR, "Failed to add gpios callbacks, err: %d", ret);
        return ret;
    }

    encoder_logger.platform_log(LOG_LEVEL::INF, "encoder init finished");
    return ret;
}

static void
update_encoder(encoder_data* encoder, float prev_angle_rad, float dt)
{
    encoder->shaft_rotate_count = (float)encoder->impulse_count / (float)CONFIG_IMPULSES_FOR_SHAFT_ROTATION;
    encoder->shaft_angle_rad    = (float)encoder->impulse_count * WRAP_TO_2PI;
    encoder->distance_m         = encoder->shaft_rotate_count * M_PI * WHEEL_DIAMETER_M;

    float const delta_angle_0       = encoder->shaft_angle_rad - prev_angle_rad;
    encoder->angular_velocity_rad_s = delta_angle_0 / dt;
    encoder->linear_velocity_m_s    = encoder->angular_velocity_rad_s * WHEEL_RADIUS_M;
}

encoders_data const&
_get_encoders_data()
{
    static float prev_angle_rad_encoder_0 = 0.0f;
    static float prev_angle_rad_encoder_1 = 0.0f;
    static float prev_robot_distance_m    = 0.0f;
    static int64_t last_timestamp_ms      = 0;

    int64_t const now_ms = k_uptime_get();
    float const dt       = (last_timestamp_ms > 0) ? (now_ms - last_timestamp_ms) * MILLI_TO_SI : 0.01f;
    last_timestamp_ms    = now_ms;

    update_encoder(&g_encoders_data.encoder_0, prev_angle_rad_encoder_0, dt);
    prev_angle_rad_encoder_0 = g_encoders_data.encoder_0.shaft_angle_rad;

    update_encoder(&g_encoders_data.encoder_1, prev_angle_rad_encoder_1, dt);
    prev_angle_rad_encoder_1 = g_encoders_data.encoder_1.shaft_angle_rad;

    g_encoders_data.robot_angle_rad =
        (g_encoders_data.encoder_1.shaft_angle_rad - g_encoders_data.encoder_0.shaft_angle_rad) *
        (WHEEL_DIAMETER_M / (2.0f * WHEEL_BASE_WIDTH_M));
    g_encoders_data.robot_distance_m =
        (g_encoders_data.encoder_0.distance_m + g_encoders_data.encoder_1.distance_m) / 2.0f;
    g_encoders_data.robot_linear_speed = (g_encoders_data.robot_distance_m - prev_robot_distance_m) / dt;
    prev_robot_distance_m              = g_encoders_data.robot_distance_m;

    return g_encoders_data;
}

void
reset_encoders()
{
    g_encoders_data = {};
}

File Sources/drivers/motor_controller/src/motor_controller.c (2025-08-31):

#pragma GCC diagnostic ignored "-Wunused-variable"

#include "motor_controller.h"
#include <stdlib.h>
#include <zephyr/drivers/gpio.h>
#include <zephyr/drivers/pwm.h>
#include <zephyr/init.h>
#include "zephyr/kernel.h"

#ifdef CONFIG_MOTOR_CONTROLLER_LOG
#include "logger.h"
#endif  // CONFIG_MOTOR_CONTROLLER_LOG

#define N_GPIO_PINS                      5u
#define DIRECTION_CONTROL_PINS_BEGIN_IDX 1u
#define PWM_PERIOD_NS                    PWM_USEC(CONFIG_PWM_PERIOD_US)

static bool g_controller_enabled = false;
static MOTORS_DATA g_motors_data = {.duty_cycle_percent_motor0 = 0u, .duty_cycle_percent_motor1 = 0u, .start = false};
static struct k_work_delayable motor_controller_work;

static struct gpio_dt_spec a_in1  = GPIO_DT_SPEC_GET(DT_NODELABEL(a_in1), gpios);
static struct gpio_dt_spec a_in2  = GPIO_DT_SPEC_GET(DT_NODELABEL(a_in2), gpios);
static struct gpio_dt_spec b_in1  = GPIO_DT_SPEC_GET(DT_NODELABEL(b_in1), gpios);
static struct gpio_dt_spec b_in2  = GPIO_DT_SPEC_GET(DT_NODELABEL(b_in2), gpios);
static struct gpio_dt_spec h_b_en = GPIO_DT_SPEC_GET(DT_NODELABEL(h_b_en), gpios);

static const struct gpio_dt_spec* gpio_pins[] = {&h_b_en, &a_in1, &a_in2, &b_in1, &b_in2};

static const struct pwm_dt_spec pwm_dc_1 = PWM_DT_SPEC_GET(DT_NODELABEL(dc_1));
static const struct pwm_dt_spec pwm_dc_2 = PWM_DT_SPEC_GET(DT_NODELABEL(dc_2));

void
set_enable_controller(bool controller_enabled)
{
    g_controller_enabled = controller_enabled;
}

void
set_start_motors(bool start)
{
    g_motors_data.start = start;
}

void
set_duty_cycle_value(int8_t duty_cycle_percent_motor0, int8_t duty_cycle_percent_motor1)
{
    if(duty_cycle_percent_motor0 > CONFIG_PWM_LIMIT)
    {
        duty_cycle_percent_motor0 = CONFIG_PWM_LIMIT;
    }

    if(duty_cycle_percent_motor0 < -CONFIG_PWM_LIMIT)
    {
        duty_cycle_percent_motor0 = -CONFIG_PWM_LIMIT;
    }

    if(duty_cycle_percent_motor1 > CONFIG_PWM_LIMIT)
    {
        duty_cycle_percent_motor1 = CONFIG_PWM_LIMIT;
    }

    if(duty_cycle_percent_motor1 < -CONFIG_PWM_LIMIT)
    {
        duty_cycle_percent_motor1 = -CONFIG_PWM_LIMIT;
    }

    g_motors_data.duty_cycle_percent_motor0 = duty_cycle_percent_motor0;

    g_motors_data.duty_cycle_percent_motor1 = duty_cycle_percent_motor1;
}

int
motor_controller_init(void)
{
    if(!device_is_ready(a_in1.port) || !device_is_ready(a_in2.port) || !device_is_ready(b_in1.port) ||
       !device_is_ready(b_in2.port) || !device_is_ready(h_b_en.port) || !pwm_is_ready_dt(&pwm_dc_2))
    {
#ifdef CONFIG_MOTOR_CONTROLLER_LOG
        platform_log("MOTOR_CONTROLLER", LOG_LEVEL_ERR, "motors pwm not ready");
#endif  // CONFIG_MOTOR_CONTROLLER_LOG
        return -ENODEV;
    }

    int ret = 0;
    ret |= gpio_pin_configure_dt(&a_in1, GPIO_OUTPUT_ACTIVE);
    ret |= gpio_pin_configure_dt(&a_in2, GPIO_OUTPUT_ACTIVE);
    ret |= gpio_pin_configure_dt(&b_in1, GPIO_OUTPUT_ACTIVE);
    ret |= gpio_pin_configure_dt(&b_in2, GPIO_OUTPUT_ACTIVE);
    ret |= gpio_pin_configure_dt(&h_b_en, GPIO_OUTPUT_ACTIVE);

    if(ret != 0)
    {
#ifdef CONFIG_MOTOR_CONTROLLER_LOG
        platform_log("MOTOR_CONTROLLER", LOG_LEVEL_ERR, "motors pins not ready");
#endif  // CONFIG_MOTOR_CONTROLLER_LOG
        return ret;
    }

#ifdef CONFIG_MOTOR_CONTROLLER_LOG
    platform_log("MOTOR_CONTROLLER", LOG_LEVEL_INF, "motors init finished");
#endif  // CONFIG_MOTOR_CONTROLLER_LOG
    return ret;
}

void
stop_motors(void)
{
    for(uint8_t i = DIRECTION_CONTROL_PINS_BEGIN_IDX; i < N_GPIO_PINS; i++)
    {
        int const ret = gpio_pin_set_dt(gpio_pins[i], 0);
#ifdef CONFIG_MOTOR_CONTROLLER_LOG
        if(ret != 0)
        {
            platform_log("MOTOR_CONTROLLER", LOG_LEVEL_ERR, "stop motors failed");
        }
#endif  // CONFIG_MOTOR_CONTROLLER_LOG
    }
}

static void
disable_controller(void)
{
    int const ret = gpio_pin_set_dt(&h_b_en, 0);
#ifdef CONFIG_MOTOR_CONTROLLER_LOG
    if(ret != 0)
    {
        platform_log("MOTOR_CONTROLLER", LOG_LEVEL_ERR, "stop controller failed");
    }
#endif  // CONFIG_MOTOR_CONTROLLER_LOG
    stop_motors();
}

static void
enable_controller(void)
{
    int const ret = gpio_pin_set_dt(&h_b_en, 1);
#ifdef CONFIG_MOTOR_CONTROLLER_LOG
    if(ret != 0)
    {
        platform_log("MOTOR_CONTROLLER", LOG_LEVEL_ERR, "enable controller failed");
    }
#endif  // CONFIG_MOTOR_CONTROLLER_LOG
}

static void
run_backward_motor(struct gpio_dt_spec* in1, struct gpio_dt_spec* in2)
{
    int err = 0;
    err |= gpio_pin_set_dt(in1, 0);
    err |= gpio_pin_set_dt(in2, 1);

#ifdef CONFIG_MOTOR_CONTROLLER_LOG
    if(err != 0)
    {
        platform_log("MOTOR_CONTROLLER", LOG_LEVEL_ERR, "Running motors backward failed");
    }
#endif  // CONFIG_MOTOR_CONTROLLER_LOG
}

static void
run_forward_motor(struct gpio_dt_spec* in1, struct gpio_dt_spec* in2)
{
    int err = 0;
    err |= gpio_pin_set_dt(in1, 1);
    err |= gpio_pin_set_dt(in2, 0);

#ifdef CONFIG_MOTOR_CONTROLLER_LOG
    if(err != 0)
    {
        platform_log("MOTOR_CONTROLLER", LOG_LEVEL_ERR, "Running motors forward failed");
    }
#endif  // CONFIG_MOTOR_CONTROLLER_LOG
}

static void
set_new_duty_cycle_value(int8_t duty_cycle_percent_motor0, int8_t duty_cycle_percent_motor1)
{
    if(duty_cycle_percent_motor0 < 0)
    {
        run_backward_motor(&a_in1, &a_in2);
    }
    if(duty_cycle_percent_motor0 >= 0)
    {
        run_forward_motor(&a_in1, &a_in2);
    }

    if(duty_cycle_percent_motor1 < 0)
    {
        run_backward_motor(&b_in1, &b_in2);
    }
    if(duty_cycle_percent_motor1 >= 0)
    {
        run_forward_motor(&b_in1, &b_in2);
    }

    uint8_t const duty_cycle_percent_motor0_scaled = (uint8_t)abs(duty_cycle_percent_motor0);
    uint8_t const duty_cycle_percent_motor1_scaled = (uint8_t)abs(duty_cycle_percent_motor1);

    uint32_t const duty_cycle_ns_motor0 =
        (PWM_PERIOD_NS * duty_cycle_percent_motor0_scaled) / (uint32_t)CONFIG_PWM_LIMIT;
    uint32_t const duty_cycle_ns_motor1 =
        (PWM_PERIOD_NS * duty_cycle_percent_motor1_scaled) / (uint32_t)CONFIG_PWM_LIMIT;

    int err = pwm_set_dt(&pwm_dc_1, PWM_PERIOD_NS, duty_cycle_ns_motor0);
    err     = pwm_set_dt(&pwm_dc_2, PWM_PERIOD_NS, duty_cycle_ns_motor1);

#ifdef CONFIG_MOTOR_CONTROLLER_LOG
    if(err != 0)
    {
        platform_log("MOTOR_CONTROLLER", LOG_LEVEL_ERR, "set pwm failed");
    }
#endif  // CONFIG_MOTOR_CONTROLLER_LOG
}

// First check start flag - stop the motors if false.
// Update motors direction and speed.
static void
update_motors_control(void)
{
    if(!g_motors_data.start)
    {
        stop_motors();
    }
    else
    {
        set_new_duty_cycle_value(g_motors_data.duty_cycle_percent_motor0, g_motors_data.duty_cycle_percent_motor1);
    }
}

static void
motor_controller_work_handler(struct k_work* work)
{
    ARG_UNUSED(work);

    if(!g_controller_enabled)
    {
        disable_controller();
    }
    else
    {
        enable_controller();
        update_motors_control();
    }
}
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

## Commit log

2025-02-03 PCB: KiCAD setup
    -create kicad project
    -add footprints,symbols and 3d models of nrf52840dongle and MPU 6050
    [Base.SLDPRT, MPU 6050 IMU.SLDASM, MPU 6050 IMU.STEP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]
2025-02-04 PCB: adding the required symbols, footprints and 3D models
    - create generic paths to the symbos and footprints, so there is no problem with setup on the other machine
    - adding further PCB elements of the project
    [282837-2--3DModel-STEP-269445.STEP, 282837-2.step, S2B-PH-K-S(LF)(SN)--3DModel-STEP-1.STEP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]
2025-02-05 PCB: Added all neecesseary symbols, footprints and 3d models
    -create an demo PCB
    -create 3dvis folder with apperance of the boards
    [1101M2S3CQE2.step, 2S 7.4V Li-PO Battery.STEP, 2S 7.4V Li-PO Battery.x_t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]
2025-02-06 PCB: Basic schematic.
    [Schematic.kicad_sch]
2025-02-06 PCB: Basic schematic - fixes.
    [Schematic.kicad_sch]
2025-02-07 PCB: completing the electrical diagram
    -fix with the H bridge (we have to use TB6612FNG which can operate at PWM 3.3 V
    -complete schematic
    -create prototype PCB schematic
    -track PCB paths
    [DOBLE PUENTE H.step, Schematic.kicad_pcb, Schematic.kicad_sch]
2025-02-07 PCB: completing the electrical diagram
    -create holes for motors installation
    -generate .gbr and .drl filles
    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
    [Schematic-B_Cu.gbl, Schematic-B_Mask.gbs, Schematic-B_Paste.gbp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]
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2025-02-07 PCBK Kicad doc
    -create a doc which is describing how to add extern symbols, footpritns
    and 3D models. It describes also how to genrate gerber files
2025-02-07 PCB; kicad doc
    -fix with link to the snapeda
2025-02-08 Drivers: Battery_level driver
    -create an structure of a driver
    -add appropriate Kconfig and CmakeLists.txx for the driver
    -make it building while CONFIG_BATTERY_LEVEL_DRV is set to y in prj.conf
    -create appropriate .overlay file for ADC to match our schematic
2025-02-08 App: small structure fixes
    -include batteryu_level.h only if CONFIG_BATTERY_LEVEL_DRV=y
    -delete uceecesseray comments
    [battery_level.c]
2025-02-09 Drivers: battery_level
    -crate an api for periodic battery level measurements
    -create an doc with appropriate description
    -use the created api in main app
2025-02-09 Drivers: quick fix to battery level drv
    -fix the path to the image from unit test
2025-02-09 App: add configuration for battery drv
    -add configuration which enable building witch CONFIG_BATTERY_LEVEL_DRV=n
    or CONFIG_BATTERY_LEVEL_DRV=y
2025-02-09 Drivers: battery-level-driver fixes
    -check if there is an registered callback before beiing called
    -check if the function which user wants to register is not NULL
    [battery_level.c]
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2025-02-13 Drivers: Battery_level driver fix
    -make a configuration which enables to perform adc mesaurements
    [battery_level.c]
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2025-02-14 Excessive clangd compilation warnings fix.
    [battery_level.c]
2025-02-17 Drivers: PMW - fix
    -fix overlay to make app building
    -add specyfic dts/bindings/pwm-dc.yaml file for our dc motors
    -removal of float calculations
    [motor_controller.c]
2025-02-21 Drivers: logger & PWM
    -add logger driver
    -add BLE configuration
    -add serial configuration
    -fix ovelray configuration to make pwm work
    -fit logger impl to motor driver
    -fit logger impl to battery driver
    -added interface(led) driver
    -fit logger impl to interface driver
    -added doc how to connect ble device from linux
    [battery_level.c, motor_controller.c]
2025-02-22 Drivers:interface/logger
    -minor chagnes in interface driver
    -add configuration to BLE stack which increase MTU and Data Len
2025-02-27 Drivers: imu
    -imu_refactoring - give data to user by callback with data structure
    -create regulator as a driver
    -regulator params can be updated with nus
    -create an callback which presents new params
2025-02-27 Fixes for making controller work - imu still not right.
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2025-02-28 drivers: imu
    -set mesurement interval to 10ms
    -add pyuthon app for connecting with ble devs
    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
2025-03-01 Asyncrhonous motor controlled worker called by regulator. Adjusted PWM period and regulator worker interval.
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2025-03-01 Motors direction based on error sign, not output.
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2025-03-02 Drivers: model identyfication driver
    -add driver which enables send input,angle,angular acceleration and time over serial
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2025-03-12 Drivers: regulator and imu
    -collect indetification data in regulator.c
    -fix imu error with wornd integration of gyro - still gyro diffr to fix
    -regulation and identification based on angle-rad and angle_dt - rad/s
    [model_identification.c]
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2025-03-13 NUS data registering in ble_logger_service. Data parser passed as callback from regulators to BLE.
2025-03-16 App: find stable configuration - robot is balancing
    - Adjust acc and gyro ranges
    - turn off dlpf
    - turn off setting mresurement interval
    - adjust PID gains
    - adjust setpoint
    - try to adjust ALPHA parameter of complementarny filter
    - There is still an problem with gyro driff - complementary filter can't elimante gyro driff which make robot fall after some time -> in my opinion we should implement
    DMP(digital montion processor) which can hanndle all filtering and calculating angle for us, and we only reads correct angle.
2025-03-18 PWM from -1 to 1, torque scaling of input signal (u) - good identification results.
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2025-04-01 IMU: Imu fixes
    -angle calculations corrections
    [imu_config.c]
2025-04-01 IMU: fixes cd
    -change parameters
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2025-04-15 PID: adjusting parameteres
    - Setpoint should be around -7.45 degrees based on IMU measurements in stable postition with disabled motor controller
    - Is is weird that regulator output is not 0 when their gains are set to 0 -> there can be porblem with NUS, we should check if the
    inserted values are interrpreted in the code correctly, for example hardcode gains to 0 and check if the output is zero.
    - H-bridge should be diagnosed and soldered again, beacuse it is weird that sometimes one of the wheel is stopping
    - We stopped at the point where robot couldn't save itself from falling independent from the direction of falling(which is correct, but it is not a
    good sign because it could be that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
2025-05-06 PID: compensate DC engine deadzone
    -to do:
    - change DC voltage
    - adjust PID params
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2025-05-29 applications:controller
    -added controller app based on nrf7002DK which enable to control
    the rotate angle of an robot using dwo buttons placed on the DK
    -nrf7002DK works as BLE central
    -controller is sending appropriate messeages which are simple text
    commands which are sending over BLE using NUS to the balancing robot
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2025-06-01 applications:controller: added rotate commands
    -refactor motor controller dirver, now setting direction is not neacceseary anmore it is set based on the set pwm value
    -adjust balance and rotate PID gains
    -change the logic of performing rotates - it is based on the one worker
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2025-07-17 drivers: encoders driver
    -added impulses and rotation calulation
    -added worker to update the encoders data periodically
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2025-07-26 drivers: NUS
    -fixed nus parsing
    [control_loop.cpp, robot_controller.cpp, robot_controller.h]
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2025-08-10 API for: setting new low-pass filter alpha coeff and using direct fedback derivative as input for D part of PID controller
2025-08-11 Robot angle validation; soft stopping motors when disabling condition occurred; general pwm ramping
2025-08-11 Failed IMU data fetch protection
    [control_loop.cpp]
2025-08-11 Additional logging on fails; proper returns handling
    [battery_level.c, encoder.c, imu_config.c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]
2025-08-11 Files with code under Sources directory; introduction of build scripts for selected boards
2025-08-12 Bluetooth driver decoupling from logger driver; removed particular zephyr inits from drivers in favor of introducing a global Drivers_Initializer class
2025-08-17 Balancing setpoint setting through NUS fixed
    [robot_controller.cpp]
2025-08-19 State machine to control the stopping/starting of the robot with the use of a button
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2025-08-31 Unwrapping of accelerometer angle obtained from atan2 to prevent very large PWM value spikes
    [robot_controller.cpp]
2025-09-04 Encoderss angle combined with gyro data to acquire rotation angle; build scripts with changed files formatting
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2025-09-28 app: added dfu_ble_smp configuration
    - enable mcuboot
    - define static partitions for dfu
    - added cli command to get current software version
    - enable smp ble
2025-10-07 schematic: added robot case model
    [54548-2271, 22 Pin FPC Connector, Raspberry Pi Zero 2 W.SLDPRT, Crystal Resonator, Raspberry Pi Zero 2 W.SLDPRT, Diode, Schottky, Raspberry Pi Zero 2 W.SLDPRT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]
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2025-10-20 Wheels speed regulator seems to have nice result - braking when too much speed e.g.
    [robot_controller.cpp, robot_controller.h]
2025-10-21 - integrated wheel speed regulators with the rest of control loop, - added a rotation PID output gain based on wheels speed to adjust to them, - added IMU and encoders reset on robot stops (both inte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
    minor:
    - swapped C++ <cmath> and <cstdlib> usages for C and Zephyr environment
    supplements.
    TODO:
    - maybe make rotation setpoint incremental (zeroing after being
    achieved?),
    - investigate if the rotation PID parameters are good enough (watch the
    logs for weird values),
    - try to investigate weird situation where robot stop and we are unable
    to resart through state ma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
    [control_loop.cpp, data_manager.cpp, encoder.c]
2025-10-22 Critical bug with PID hysteresis approach fix
    [robot_controller.cpp, robot_controller.h]
2025-10-22 IMU recalibration after fall; removing D part of rotation controller - can be reintroduced after ramping rotation setpoint, since now it can cause very large spikes
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2025-10-28 Initial distance controller implementation - stays in place and follows setpoint (can overshoot - to be tuned)
    [encoder.c, robot_controller.cpp, robot_controller.h]
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2025-10-30 Linear speed PID control - robot drives with constant speed, braking when reaching target (small overshoot)
    [encoder.c, robot_controller.cpp, robot_controller.h]
2025-10-31 Minor renaming with state machine flags resetting - solving critical bug on possible multiple flags being stored
    [robot_controller.cpp, robot_controller.h, state_machine.cpp]
2025-11-01 Namespace introducing in missing places, flags in MSM made as private struct (removing previous mistake)
    [control_loop.cpp, data_manager.cpp, drivers_initializer.cpp]
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2025-12-15 mathematical model: added identification data
    [ident_20250910_010719.csv, ident_20250910_011357.csv, ident_20250910_011740.csv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]
2025-12-16 model: added better identification data
    -stable sampling time 50ms
    -longer merged data
    [ident_20250910_010719.csv, ident_20250910_011357.csv, ident_20250910_011740.csv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]
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2026-02-19 mathematical model: derive robot model based on identification .csv data
    [robot_identification_side_backward_0.csv, robot_identification_side_backward_1.csv, robot_identification_side_backward_2.csv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]
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2026-08-29 rpi_camera: switch from RTSP/H.264 (MediaMTX) to TCP MJPEG for zero latency
    - Replace MediaMTX with rpicam-vid streaming MJPEG directly over TCP on port 8555.
    - Eliminate H.264 inter-frame compression overhead: H.264 required complex key and delta frame tracking, forcing FFmpeg/OpenCV to build an aggressive ~500ms decoding buffer queue that ruined real-time control.
    - Adopt self-contained JPEG frames: MJPEG transmits each frame as an independent, complete image, allowing OpenCV to grab and process fresh visual data instantly without predictive frame buffers.
    - Bypass RTSP protocol and HTTP wrappers: Connecting straight to a raw TCP socket eliminates network overhead, proxy layers, and handsh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
2026-09-19 - fix a bug that right application widget was frozen, when re-connection was done after a connection loss and DFU was skipped (enhance dfu_ble.cpp), - go back to incremental setpoints: distance and r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
    [robot_controller.cpp]
2026-09-28 Fix of feedback values
    [robot_controller.cpp]
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
